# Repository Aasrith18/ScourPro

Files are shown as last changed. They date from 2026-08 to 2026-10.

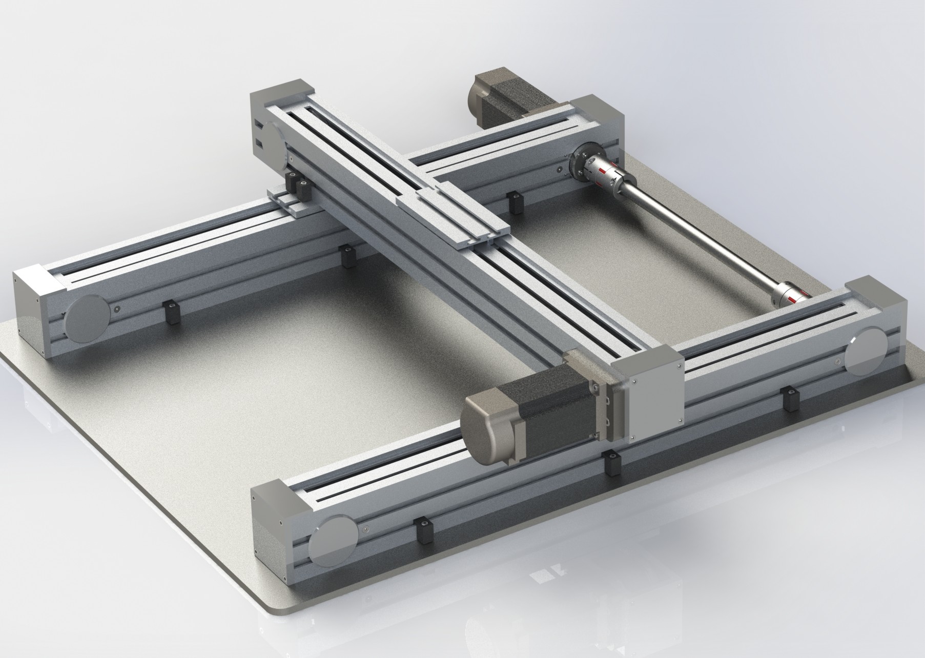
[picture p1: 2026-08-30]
CAD files/ASM-2.JPG

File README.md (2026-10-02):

# ScourPro: Automated sand bed profiler for laboratory flumes
This project is a sand bed profiler aimed specifically at scour profiling on the Hydraulic laboratory flumes. This file clearly documents the progress of this project (failures & the knowledge acquired from them) and also outlines the requirements, scope and direction for the final product.

### Visual Prototype: Hero image, Project overview, Output visualization

<p align="center">
  <em>Final product visualization</em>
</p>

<p align="center">
  <em>Product overview with major components, features & specifications</em>
</p>

<p align="center">
  <em>Expected output visualization</em>
</p>

## Table of Contents

1. [Introduction](#1-introduction)
2. [Components Used](#2-components-used)
3. [Work Done So Far](#3-work-done-so-far)
4. [Wiring Diagram](#4-wiring-diagram)
5. [Hardware Instructions](#5-hardware-instructions)
6. [Code Overview](#6-code-overview)
7. [Future Plans](#7-future-plans)
8. [License](#8-license)
9. [Repository Structure](#9-repository-structure)
10. [Credits & Acknowledgements](#10-credits--acknowledgements)

## 1. Introduction
This project aims to speed up the surface profiling process on the laboratory flumes by automatically moving a sensor, along x-direction (width) and y-direction (length), which measures the depth (z-direction) of the sand bed surface. 

## 2. Components Used
A detailed Engineering Bill of Materials (EBOM) is provided [here](https://docs.google.com/spreadsheets/d/1VOksqOdsrbbUIk9T7hXksDzNJ4-1fR_ZSVMrzwDk07w/edit?usp=sharing).

| Components (embedded) | Quantity | Notes |
|---|---|---|
| Raspberry Pi Pico| 1 | Micro controller |
| NEMA17 stepper motor| 3 | Stepper motor |
| A4988 Stepper Motor Driver Module| 3 | Stepper motor driver |
| 24V 5A DC Power Supply Adapter | 1 | Main power source |
| DC-DC Automatic Boost Buck Converter Board  | 1 | Power source for servos |
| Misc. components | ~ | Jumper wires, breadboard, etc. |

| Components (hardware) | Quantity | Notes |
|---|---|---|
| 2020 V-Slot Aluminium Extrusion Profile 1000 mm (For frame) | - | - |
| V-Wheel Kit & Connecting Plates (For custom mounting) | - | - |
| 3D Printed Parts | - | Provided in `/CAD files` folder  |
| Misc. Hardware | - | Screws, bearings, etc. |

## 3. Work Done So Far
I started this project with - a stepper motor (NEMA17), stepper motor driver (DM556), microcontroller (Raspberry Pi Pico 2), 24V power supply.
Using DM556 stepper motor driver was an overkill so it was replaced with A4988 stepper motor driver.
After a lot of effort, the correct wiring for the NEMA17 motor was figured out. It is shown in the [wiring diagram](#4-wiring-diagram) section below.

After the raspberry pi pico 2 is burnt (my bad), I shifted to raspberry pi pico (coz I didn't see any difference between them, at least for the project requirements 🤷‍♂️).
Testing was then done with a 12V power supply and A4988 stepper motor driver. The code file along with the libraries used is shared in the [code overview](#6-code-overview) section below.

After testing different options for the achieving higher speeds for the motor, these parameters are suggested. (just a suggestion)
24V power supply, 1-1.2 A current (adjustable on A4988 motor driver).

The initial version of this project was quite flimsy but good enough to work with during motor testing. I've uploaded a video (sped up) from when the motor first worked.
Although, there are some **important** things to note regarding the codes given in this repo {[code overview](#6-code-overview)}:
- The 323 revolutions, hardcoded, is the total number of revolutions it takes to get from one end of the lead screw to the other (found out the hard way 😮‍💨). You may or may not need this. So to you, this is a variable you need to adjust after the hardware is setup. If you don't want to hardcode it and provide input options for width and length to be covered, then that would be great as well.
- The steps per revolution are 400. I've tried decreasing and increasing them but the motor either stopped or made a lot of noise. I couldn't figure out why the others weren't working even though I adjusted both motor driver and the code accordingly. (lack of knowledge on my part. you can still give this a try. 🙂)
- During the "Phase 2" of the motor movement (check in code), the motor is coded to stop for 1 sec after every 10 revolutions. This was done when the sensor was not in picture. And different experiments may require different resolution while taking a reading. And there's another thing to consider - the "tracking" feature of the sensor (basically, continuous readings without us having to send transmit command every time). Leave it as it is for testing the motor, but this will change based on the hardware setup and the sensor you get.

https://github.com/user-attachments/assets/a4b7bfc3-b2b1-426d-8927-acc9cb2e59b3
<p align="center">
  <em>Initial version of working motor set up</em>
</p>

I also got a distance measurement sensor from [Meskernel LDL-10](https://www.meskernel.com/laser-distance-moudules/65904266.html). No proper documentation was available for this sensor.
It is pretty easy to use with a USB connection but I couldn't figure how to use it with a UART connection.
Unfortunately, till date, this sensor is the only feasible option we have. So if you're going to use it.. all the best 👍

In that (worst case) scenario, here are some notes regarding the sensor:
- The module I used was U85B, it only worked with the baud rate of 19200.
- For using it with USB connection, you need to download the [meskernel software](https://lasersensor.net/en/download/software/).
- This module had an RTS pin. I never found out what it is or does. Nor did I find any documentation of this sensor mentioning an RTS pin. 🧐 
So I never got to use it with a UART connection and the sensor got damaged before I could figure it out.
- Other modules may come with other problems, I'll let you discover them. 😄

Sensor readings on software
<p align="center">
  <em>Test readings I took with USB connection</em>
</p>

## 4. Wiring Diagram
wiring_img
<p align="center">
  <em>Wiring Diagram for the NEMA17 motor with A4988 stepper motor driver</em>
</p>

## 5. Hardware Instructions
The [CAD files](/CAD%20files/) folder contains all the necessary files. But, before you print them out, make sure to check the dimensions. The files were made with a general idea of the product and not tailored to a specific flume dimensions. Please pick a flume you wish to work on and alter the dimensions accordingly 🙂 I suggest you first run a trial with 3D printed components before fabricating any metal components.

## 6. Code Overview
This project involves MicroPython code file (singular) to communicate with the A4988 motor driver. I've uploaded the file in this repository.
I also uploaded the file to communicate with DM556 motor driver as well (just in case). The code paths are below.

> 📁 Code Path: [`rasppi-a4988.py`](rasppi-a4988.py)

> 📁 Code Path: [`rasppi-dm556.py`](rasppi-dm556.py)

Two libraries **(machine and time)** are used in the code.
- Machine library:
  What it is: The machine library is a core MicroPython module used to directly interact with the microcontroller's physical hardware.
  What it is doing in this code:  Pin Initialization - It designates the Raspberry Pi Pico's GPIO pins (Step, Direction, Enable, and the onboard LED) as output pins using machine.Pin.OUT.
  Digital Signaling: It toggles these pins High or Low (using .on(), .off(), and .value()) to physically communicate with the A4988 driver. This manages the motor's spin direction, actively enables or disables the driver module, and triggers the physical step actions. 

- Time library:
  What it is: The time module handles time-tracking, scheduling, and blocking delays.
  What it is doing in this code:  Precise Motor Pulsing (Microseconds): It uses time.sleep_us() to create extremely short, calculated microsecond delays. This is used to form the active 25% duty cycle step pulses required to accurately turn the motor at a specific frequency.
  Sequence Pacing (Seconds): It uses the standard time.sleep() function to introduce longer pauses. This controls the 1-second gaps when blinking the Pico's LED to signal startup, as well as the programmed 1-second resting periods every 10 revolutions during the motor's second phase of movement.  

## 7. Future Plans
- Find a feasible sensor that meets the following requirements:
  - Precision: 1 mm
  - Accuracy: +/- 1 mm
  - Range: 1-2 m
  - Should be able to detect the distances of granular surfaces like sand
  - Should have robust documentation
  - Should detect distances of a point, instead of averaging out the entire field of view.
  - Laboratory purposes. Need not be industrial.
  - Budget friendly
- Fabricate light weight metal (aluminum mostly) components for hardware and assemble them together.

## 8. License
Licensed under the **GNU General Public License v3.0 (GPL-3.0)**.  
See the [LICENSE](./LICENSE) file for full details.

## 9. Repository Structure

```text
ScourPro/
├── CAD files/            # 3D printed parts and custom mounting CAD files
├── .gitignore            # Git ignore rules
├── LICENSE               # GNU GPL-3.0 License
├── Product_Specs.md      # Product Requirements & Specifications Document
├── README.md             # Project documentation, wiring specs, and future scope
├── rasppi-a4988.py       # MicroPython script for Raspberry Pi Pico with A4988 driver
└── rasppi-dm556.py       # Alternative MicroPython script for DM556 driver
```

## 10. Credits & Acknowledgements

* **Project Guidance:** Special thanks to **Prof. Dhrubajyoti Sen** and the **Hydraulics Laboratory, Department of Civil Engineering** for their continuous support, mentorship, and resources throughout the development of this project.
* **Open Source Community:** Grateful to the MicroPython core development team for providing robust libraries (`machine`, `time`) that simplified microcontroller interfacing.
* **Hardware & Components:** Acknowledgements to the manufacturers and hardware suppliers for providing open specifications and modules (Raspberry Pi Foundation, Allegro MicroSystems for the A4988 driver).

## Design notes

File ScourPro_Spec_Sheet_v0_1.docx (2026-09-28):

ScourPro

Automated Scour Surface Profiler — Product Specification Sheet — Proof-of-Concept (P1)

Document ID | SCOURPRO-SPEC-P1-v0.1
Status | DRAFT — duplicate this file per revision
Prepared by | TBD
Reviewed / Approved by | TBD
Date | TBD
Applicable prototype | P1 (Proof-of-Concept)
Target users | Indian hydraulics research & teaching labs (IITs, NITs, CWPRS)

How to use: fill Target values at design freeze; fill Measured values only from documented tests (link test report ID in Notes). Any cell left TBD blocks release sign-off. Duplicate the file and bump the version for each iteration; log changes in §12.

1. Product Overview

Product name / SKU | ScourPro
Target users | Indian hydraulics research & teaching labs (IITs, NITs, CWPRS)
Primary use case | Automated scour bed profiling after drained flume tests
Configuration | 2-axis Cartesian gantry: GT2 belt-driven X (width) and Y (length); sensor fixed (no Z motion axis)
Measurement principle | Single-point non-contact depth reading at each X–Y grid point; sensor moved over the bed, ToF reading gives depth
Mounting | Bolt-down to a fixed rail on the flume side walls
Target flume | 0.5 m (L) × 0.3 m (W) × 0.8 m (H); PoC fixed to 0.3 m width
Not-to-exceed build cost | ₹60,000 (PoC ceiling)

2. Measurement & Motion Performance

Accuracy verified after multi-point calibration against a stepped datum block, checked on a sand-textured (matte) reference surface. Report test ID in Notes.

Parameter | Minimum | Target | Measured | Test method / Notes
Motion axes | 2 | 2 (X, Y) | TBD | Belt X + belt Y; sensor fixed
Depth accuracy | ±5 mm | ±1 mm | TBD | Multi-point calibration; ISO-style repeat reads
Depth resolution / precision | 1 mm | ≤0.5 mm | TBD | Repeat reads, static target
XY positioning accuracy | ±1 mm | ±0.5 mm | TBD | Commanded vs. measured, dial gauge
X travel (width) | 300 mm | 300 mm | TBD | Full flume cross-section
Y travel (length) | 500 mm | 500 mm | TBD | Along flume length
Grid spacing (user-set) | 10 mm | 10–50 mm | TBD | Configurable per run
Z measurement window | TBD | TBD | TBD | Must cover full scour depth (~150 mm) from fixed height
Full-grid scan time | ≤20 min | ≤10 min | TBD | Representative grid, full area

2.1 Work Envelope

Parameter | Minimum | Target | Measured | Test method / Notes
X-axis travel (width) | 300 mm | 300 mm | TBD | Hard stop + soft limit values
Y-axis travel (length) | 500 mm | 500 mm | TBD | Hard stop + soft limit values
Sensor standoff height | TBD | TBD | TBD | Fixed; set to cover full depth range
Flume width compatibility | 0.3 m | 0.3 m | TBD | PoC fixed; adjustable is a later item

3. Actuation & Transmission

Parameter | Minimum | Target | Measured | Test method / Notes
Motor type (X, Y) | TBD | TBD | TBD | Stepper; NEMA 17 class expected
Driver | TBD | TBD | TBD | A4988 / TMC2209 class; driven by Pico
Transmission (X) | GT2 6 mm belt | GT2 6 mm belt | TBD | Open-ended, anchored both ends
Transmission (Y) | GT2 6 mm belt | GT2 6 mm belt | TBD | Dual-side drive to resist racking
Homing / limit switches | Required (both axes) | Required (both axes) | TBD | Home every run for repeatable origin
Power-off position hold | TBD | TBD | TBD | Belt is not self-locking; evaluate need

4. Materials & Structure

General structure | V-slot aluminium extrusion (frame doubles as linear rail)
Brackets & mounts | 3D-printed (PETG/ASA recommended; document print params)
Linear motion | V-wheels on extrusion; eccentric spacers for preload
Moisture / corrosion | Splash-resistant only (bed is drained before use)
Prohibited | PLA in load-bearing structural paths (creep)

Acceptance criterion: positioning and depth-accuracy specs in §2 govern structural adequacy — not material choice per se.

5. Electrical & Power

Parameter | Minimum | Target | Measured | Test method / Notes
Input supply | 12 V DC | 24 V DC | TBD | Single PSU; state final value at build
Logic supply | 5 V | 5 V | TBD | Buck converter from main rail; do not power Pico off motor rail
Controller | RPi Pico | RPi Pico | TBD | Drives steppers via drivers
External interface | USB | USB (PoC) → Wi-Fi (final) | TBD | USB to laptop for PoC; Wi-Fi is a later item
Driver decoupling | Required | Required | TBD | Bulk capacitor across each driver motor-supply
Inline fuse | Required | Required | TBD | On main supply

6. Control & Software

Parameter | Minimum | Target | Measured | Test method / Notes
Firmware | MicroPython | MicroPython | TBD | On the Pico
Operation | Grid + spacing entry, start | Same, refined UI | TBD | Automated raster scan
Output format | CSV (x, y, z) | CSV + plot + heatmap | TBD | CSV for PoC; visuals in later versions
3D surface generation | Off-device (post) | Off-device (post) | TBD | Python / ParaView from CSV
Calibration | Multi-point datum block | Guided routine | TBD | Stepped block, matte/sand surface

7. Environment, Safety & Compliance

Parameter | Minimum | Target | Measured | Test method / Notes
Operating temperature | 10 °C | 10–80 °C | TBD | Indoor lab; per user spec
Ingress protection | None (PoC) | None (PoC) | TBD | Basic enclosure; no formal IP rating for PoC
Compliance | None (research PoC) | None (research PoC) | TBD | Research prototype; not a sold product

8. Mechanical & Interfaces

Flume attachment | Rail with leveling feet resting on / bolted to both side walls
Leveling | Adjustable feet; rail plane defines the Z datum for all depth readings
Sensor interface | Fixed sensor housing on the trolley (no moving Z axis)
Cable routing | Drag chain along the beam; keep cables off the moving bed

9. Reliability, Serviceability & Lifecycle

Parameter | Minimum | Target | Measured | Test method / Notes
Duty rating | Occasional lab use | Occasional lab use | TBD | Not continuous / production duty
Belt service interval | TBD | TBD | TBD | Inspect tension periodically
Spares | TBD | TBD | TBD | Printable bracket STLs published

10. Acceptance Test Matrix

Every Measured cell above must trace to a row here. One report per test, filed by ID.

Test ID | Test | Method / Standard | Pass criterion
T-01 | Depth accuracy | Multi-point datum block, matte surface, repeat reads | Within ±1 mm of target (§2)
T-02 | XY positioning accuracy | Commanded vs. measured, dial gauge | Within ±0.5 mm target (§2)
T-03 | Full-grid scan time | Representative grid over full area | ≤ target (§2)
T-04 | Homing repeatability | Repeated home + return to reference point | Origin repeatable within XY spec
T-05 | Calibration routine | Run datum-block calibration, verify fit | Residuals within depth accuracy spec
T-06 | Belt racking (Y) | Full Y travel, check beam squareness | No skew / bind across travel
T-07 | End-to-end scan | Full scan of a real scoured bed, export CSV | Complete grid, no missed points

11. Open Engineering Items

- Sensor selection on sand — confirm the chosen ToF/laser sensor holds ±1 mm on matte, possibly damp sand across the full depth range (bench test before design freeze).
- Z measurement window — fix the sensor standoff height so the depth window covers the full ~150 mm scour depth without moving; this drives the sensor spec.
- No-Z fallback — with no motion Z axis there is no contact-probe backup; decide whether a fallback is needed if the ToF underperforms.
- Belt racking on the 500 mm Y axis — single vs. dual-side drive, or a stiff enough beam; confirm before build.
- Rail leveling / datum — rail flatness along Y directly biases depth; decide leveling method vs. a per-point correction map.
- Power-off hold — belts don't self-lock; determine whether holding torque or a brake is required.

12. Revision Log

Rev | Date | Author | Changes
v0.1 | TBD | TBD | Initial PoC draft

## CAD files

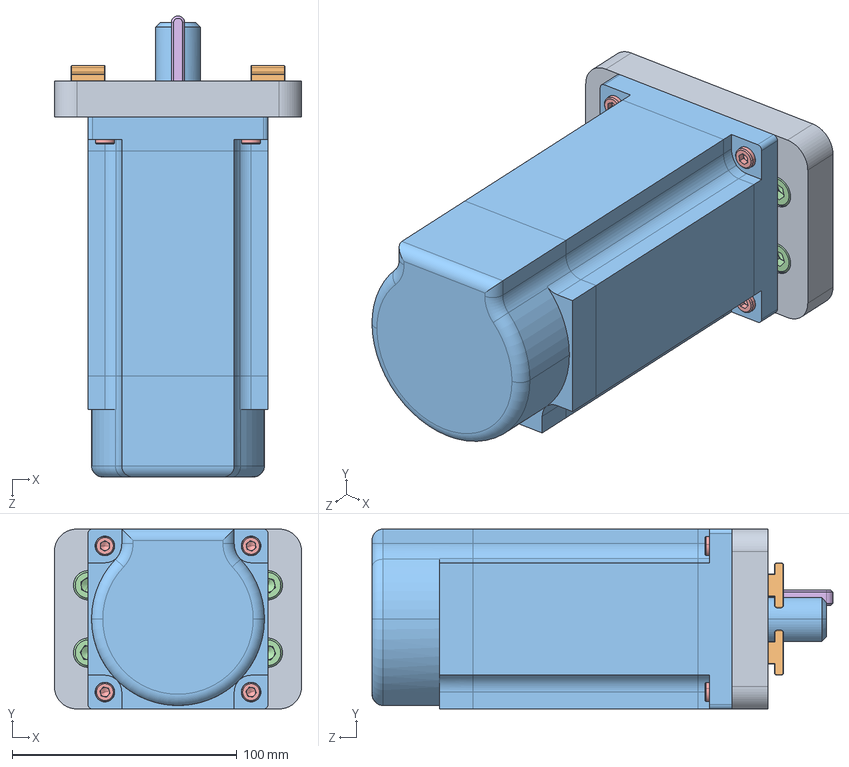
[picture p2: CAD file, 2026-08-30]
CAD files/MTR-HLD_ASM.STEP
110.0 x 80.0 x 205.0 mm
PRT-21
PRT-20 x 4
MTR
socket head cap screw_am_B18.3.1M - 8 x 1.25 x 12 Hex SHCS -- 12NHX x 4
socket head cap screw_am_B18.3.1M - 5 x 0.8 x 20 Hex SHCS -- 20NHX x 4
PRT-24

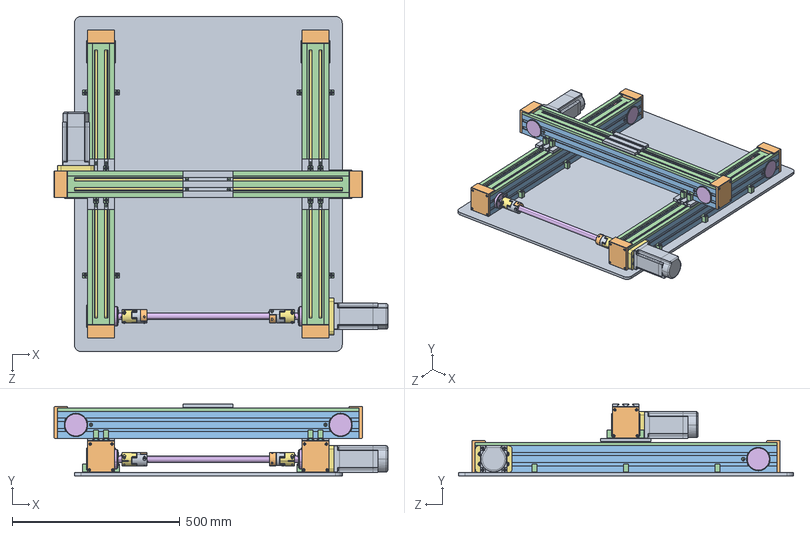
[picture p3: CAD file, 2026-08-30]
CAD files/ASM-2.STEP
996.0 x 214.0 x 1000.0 mm
BSE_PLT
PRT-1 x 6
PRT-2 x 6
PRT-18 x 3
PRT-5 x 12
PRT-4 x 6
BLT x 3
PRT-16 x 3
PRT-17 x 6
PRT-15 x 3
PRT-14 x 6
socket head cap screw_am_B18.3.1M - 3 x 0.5 x 10 Hex SHCS -- 10NHX x 24
socket countersunk head screw_am_B18.3.5M - 5 x 0.8 x 30 Socket FCHS -- 30N x 6
PRT-7 x 8
PRT-12 x 3
PRT-19 x 12
PRT-13 x 3
needle roller bearing_nm_am_AFBMA 18.1.3.4 - 45NM13 - 34,DE,AC,34 x 12
socket head cap screw_am_B18.3.1M - 5 x 0.8 x 20 Hex SHCS -- 20NHX x 32
socket countersunk head screw_am_B18.3.5M - 5 x 0.8 x 25 Socket FCHS -- 25N x 24
socket countersunk head screw_am_B18.3.5M - 3 x 0.5 x 6 Socket FCHS -- 6N x 48
PRT-6 x 2
PRT-8 x 2
PRT-9 x 2
PRT-10 x 2
PRT-11 x 2
PRT-23 x 4
socket head cap screw_am_B18.3.1M - 5 x 0.8 x 12 Hex SHCS -- 12NHX x 8
PRT-22 x 2
PRT-25
PRT-21 x 2
PRT-20 x 15
MTR x 2
socket head cap screw_am_B18.3.1M - 8 x 1.25 x 12 Hex SHCS -- 12NHX x 8
PRT-24 x 2
PRT-3 x 19
socket head cap screw_am_B18.3.1M - 5 x 0.8 x 25 Hex SHCS -- 25NHX x 19
socket head cap screw_am_B18.3.1M - 5 x 0.8 x 16 Hex SHCS -- 16NHX x 16

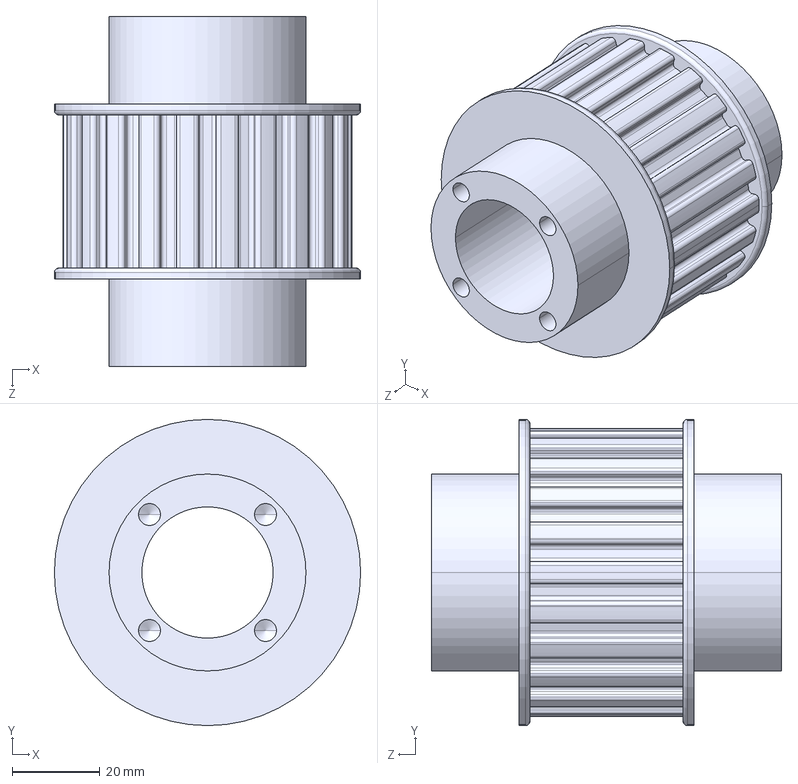
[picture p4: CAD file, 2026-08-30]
CAD files/PRT-4.STEP
70.0 x 70.0 x 80.0 mm

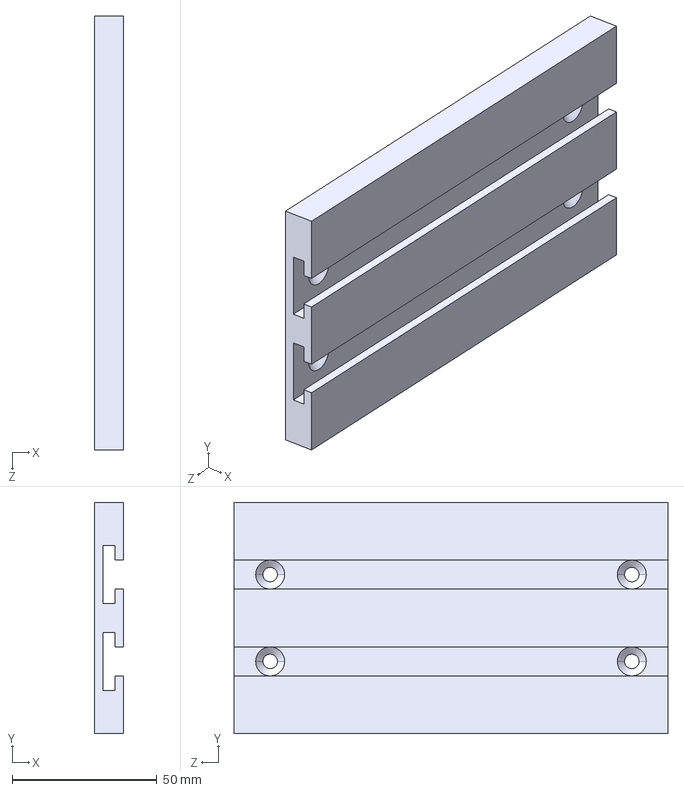
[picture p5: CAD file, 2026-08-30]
CAD files/PRT-13.STEP
10.0 x 80.0 x 150.0 mm

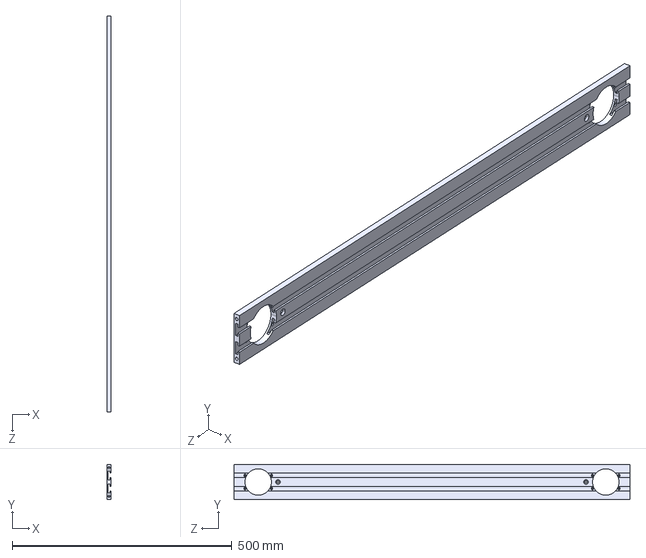
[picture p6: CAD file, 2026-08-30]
CAD files/PRT-2.STEP
10.0 x 80.0 x 900.0 mm

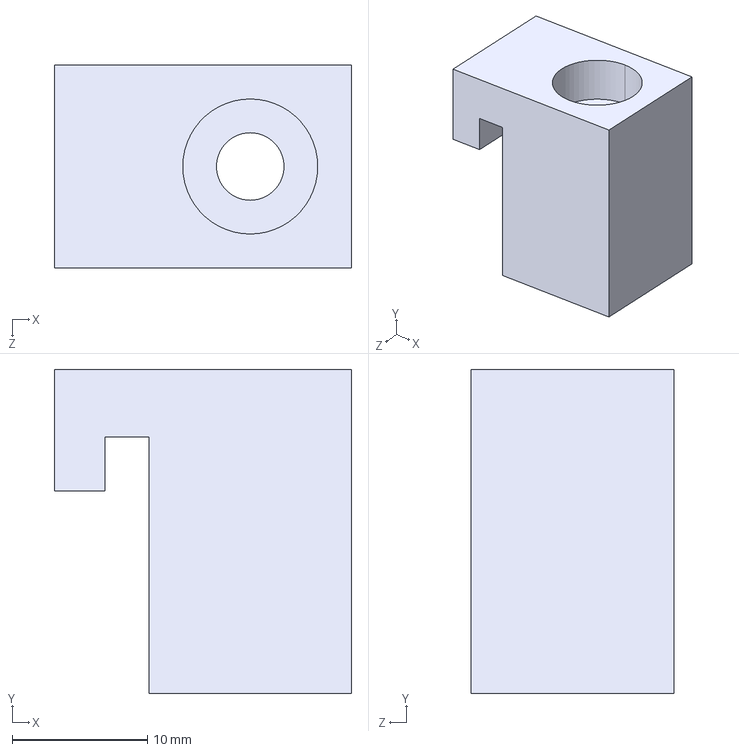
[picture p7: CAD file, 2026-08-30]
CAD files/PRT-3.STEP
22.0 x 24.0 x 15.0 mm

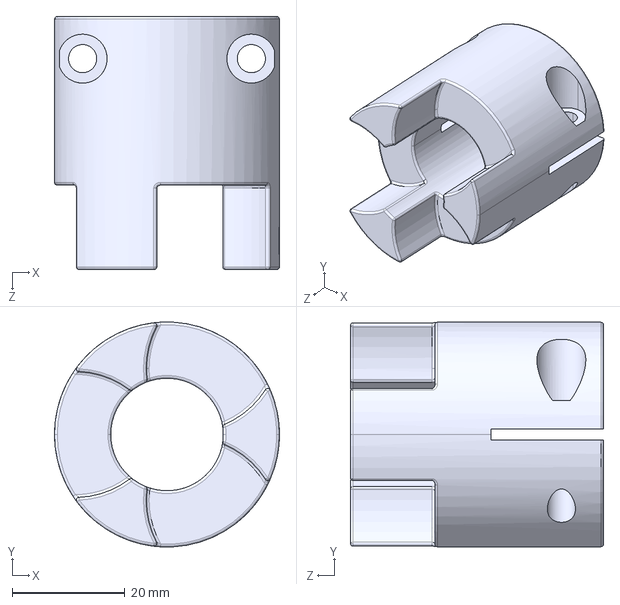
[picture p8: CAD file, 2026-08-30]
CAD files/PRT-8.STEP
40.0 x 39.9 x 45.0 mm

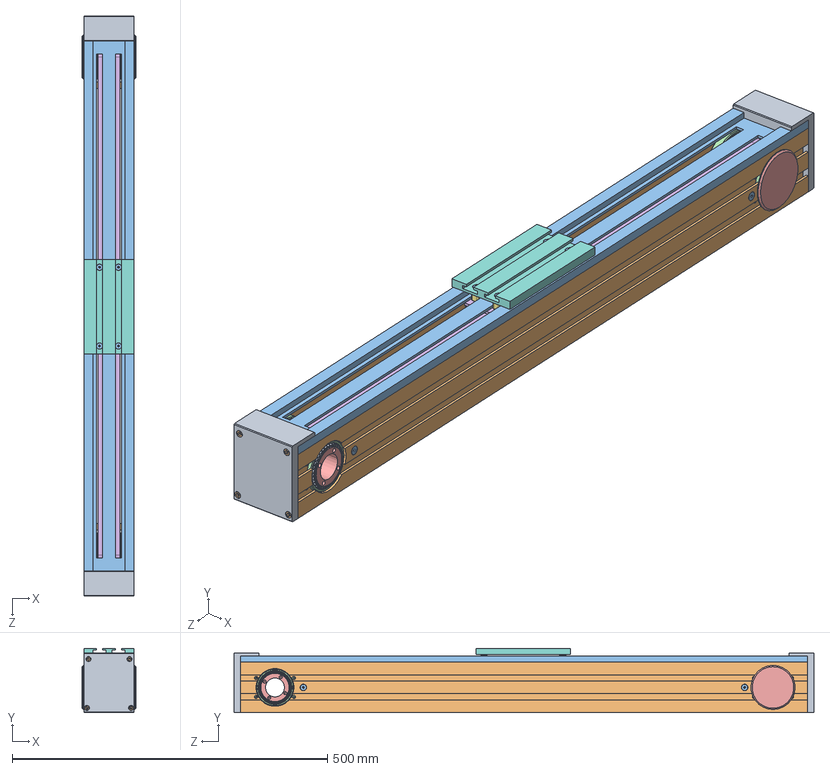
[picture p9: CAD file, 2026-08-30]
CAD files/BLT-ACT_ASSEM.STEP
86.0 x 102.0 x 920.0 mm
PRT-1 x 2
PRT-2 x 2
PRT-18
PRT-5 x 4
PRT-4 x 2
BLT
PRT-16
PRT-17 x 2
PRT-15
PRT-14 x 2
socket head cap screw_am_B18.3.1M - 3 x 0.5 x 10 Hex SHCS -- 10NHX x 8
socket countersunk head screw_am_B18.3.5M - 5 x 0.8 x 30 Socket FCHS -- 30N x 2
PRT-7 x 2
PRT-12
PRT-19 x 4
PRT-13
needle roller bearing_nm_am_AFBMA 18.1.3.4 - 45NM13 - 34,DE,AC,34 x 4
socket head cap screw_am_B18.3.1M - 5 x 0.8 x 20 Hex SHCS -- 20NHX x 8
socket countersunk head screw_am_B18.3.5M - 5 x 0.8 x 25 Socket FCHS -- 25N x 8
socket countersunk head screw_am_B18.3.5M - 3 x 0.5 x 6 Socket FCHS -- 6N x 16

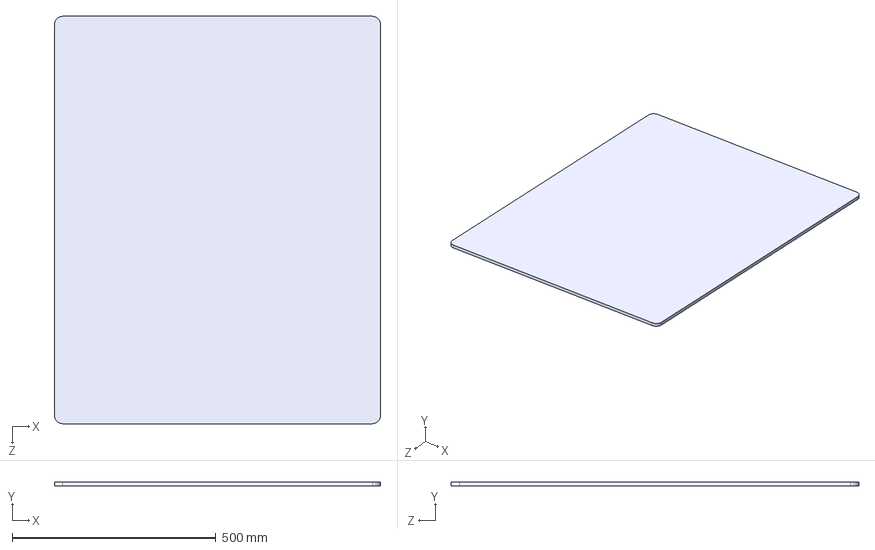
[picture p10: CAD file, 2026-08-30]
CAD files/BSE_PLT.STEP
800.0 x 10.0 x 1000.0 mm

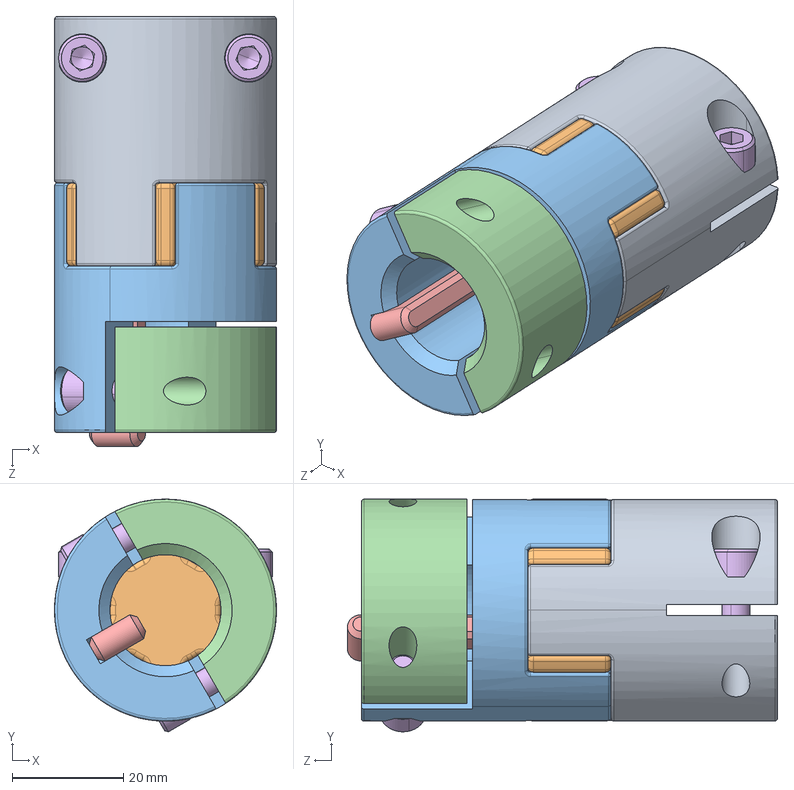
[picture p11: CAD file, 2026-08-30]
CAD files/CUP_ASSEM.STEP
40.0 x 41.9 x 77.5 mm
PRT-8
PRT-9
PRT-10
PRT-11
PRT-23
socket head cap screw_am_B18.3.1M - 5 x 0.8 x 12 Hex SHCS -- 12NHX x 4

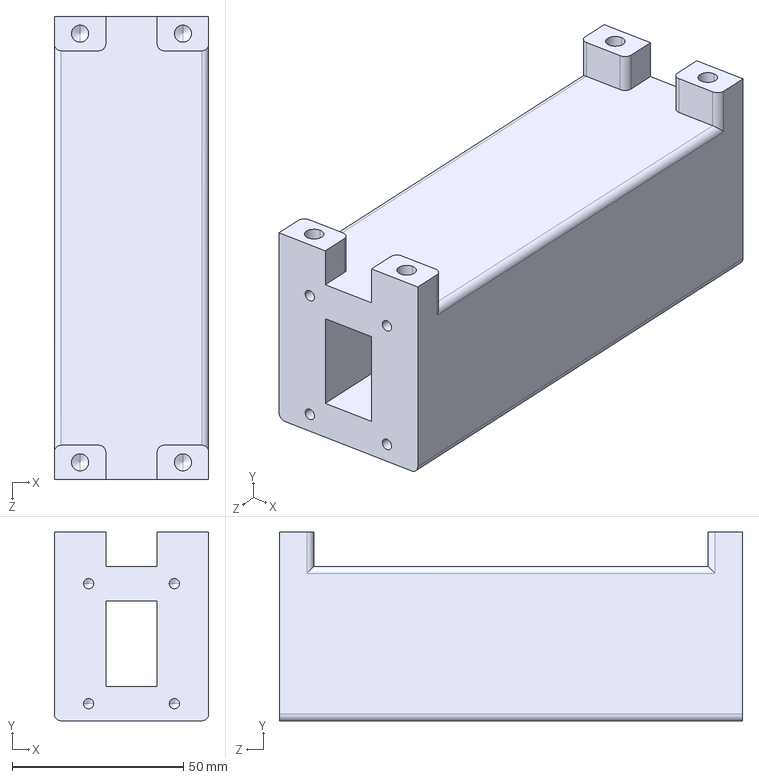
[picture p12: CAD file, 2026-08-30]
CAD files/PRT-16.STEP
45.0 x 55.0 x 135.0 mm

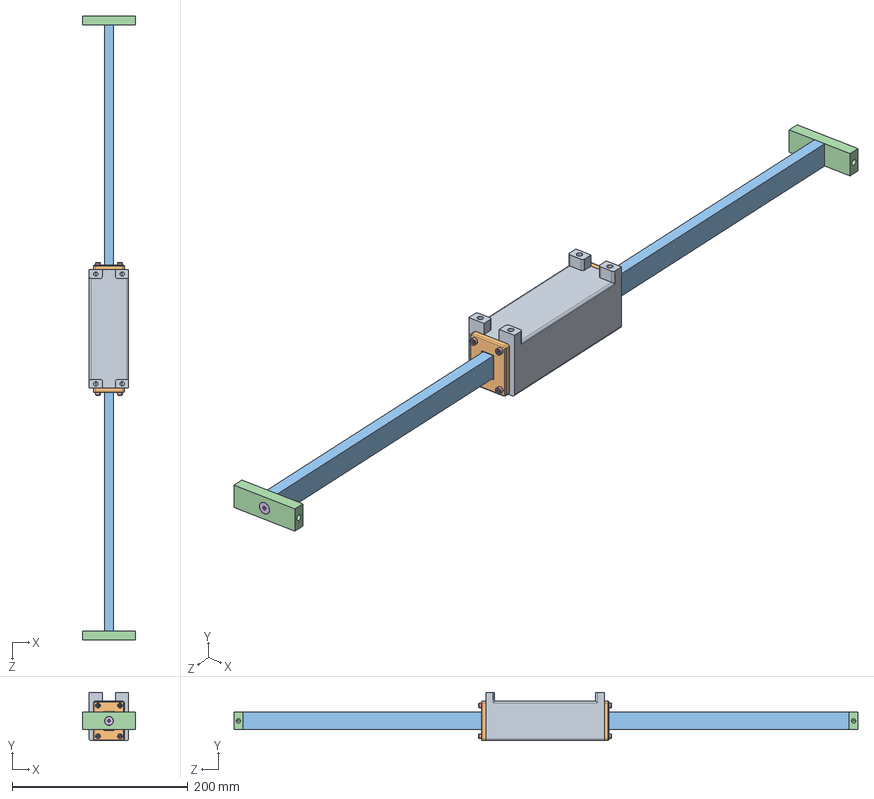
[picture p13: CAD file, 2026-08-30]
CAD files/SLD_ASSEM.STEP
60.0 x 55.0 x 710.0 mm
PRT-16
PRT-17 x 2
PRT-15
PRT-14 x 2
socket head cap screw_am_B18.3.1M - 3 x 0.5 x 10 Hex SHCS -- 10NHX x 8
socket countersunk head screw_am_B18.3.5M - 5 x 0.8 x 30 Socket FCHS -- 30N x 2

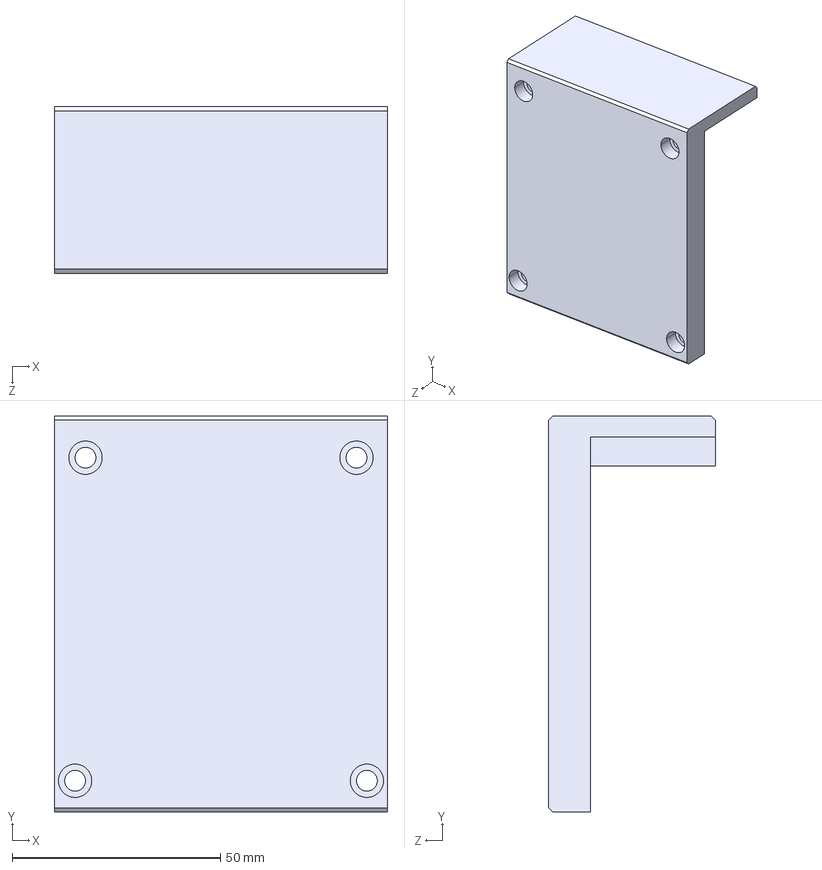
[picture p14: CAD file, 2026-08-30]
CAD files/PRT-1.STEP
80.0 x 95.0 x 40.0 mm

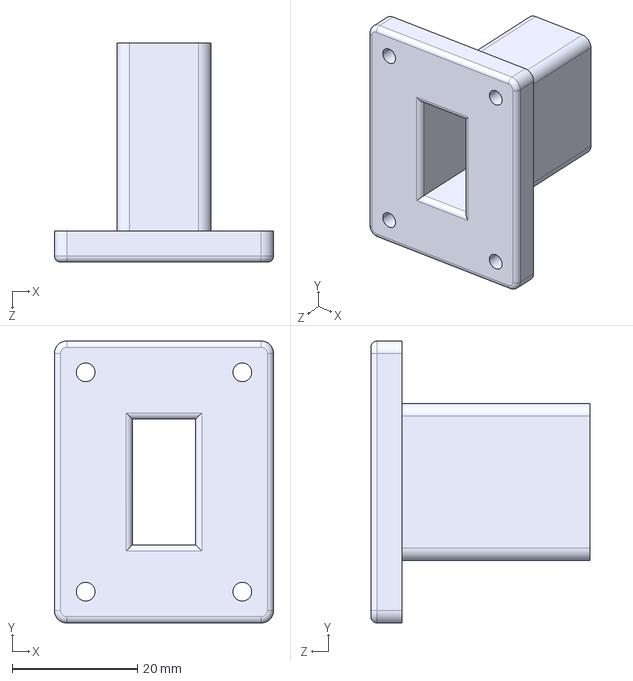
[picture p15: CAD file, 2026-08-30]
CAD files/PRT-17.STEP
35.0 x 45.0 x 35.0 mm

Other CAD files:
CAD files/PRT-22.STEP

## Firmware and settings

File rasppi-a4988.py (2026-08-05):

import machine
import time

# Pin configuration
ENABLE_PIN = 10   # Active LOW on A4988 — pull LOW to enable motor
STEP_PIN   = 11
DIR_PIN    = 12
LED_PIN    = "LED"

# Motor configuration
# A4988 microstepping (set MS1/MS2/MS3 pins or jumpers on the board):
#   Full step   → 200 steps/rev
#   Half step   → 400 steps/rev
#   Quarter     → 800 steps/rev
#   Eighth      → 1600 steps/rev
#   Sixteenth   → 3200 steps/rev
STEPS_PER_REV = 400   # Assumes half-step mode on A4988 !!DON'T CHANGE!!
DUTY_CYCLE    = 0.25  # 25%

# Setup pins
step   = machine.Pin(STEP_PIN,   machine.Pin.OUT)
dirpin = machine.Pin(DIR_PIN,    machine.Pin.OUT)
enable = machine.Pin(ENABLE_PIN, machine.Pin.OUT)
led    = machine.Pin(LED_PIN,    machine.Pin.OUT)

# Enable the driver (active LOW)
enable.off()

def blink_led(times, gap):
    """Blink onboard LED a given number of times with a gap (in seconds)."""
    for _ in range(times):
        led.on()
        time.sleep(1)
        led.off()
        time.sleep(gap)

def pulse_step(freq_hz=1000):
    """
    Send a single step pulse at 25% duty cycle.
    A4988 minimum pulse width: 1µs HIGH, 1µs LOW — well within these timings.
    """
    period_us   = int(1_000_000 / freq_hz)
    on_time_us  = int(period_us * DUTY_CYCLE)
    off_time_us = period_us - on_time_us

    step.on()
    time.sleep_us(on_time_us)
    step.off()
    time.sleep_us(off_time_us)

def rotate(revolutions, dir_val, freq_hz=1000, pause_every=None, pause_duration_s=0):
    """
    Rotate the motor for a given number of revolutions.
    """
    dirpin.value(dir_val)
    total_steps = revolutions * STEPS_PER_REV

    for s in range(1, total_steps + 1):
        pulse_step(freq_hz)
        if pause_every is not None:
            if s % (pause_every * STEPS_PER_REV) == 0:
                time.sleep(pause_duration_s)

def shutdown():
    """Disable driver to reduce heat when idle."""
    enable.on()  # Active LOW, so HIGH = disabled

# ── MAIN SEQUENCE ────────────────────────────────────────────────

blink_led(times=3, gap=1)

print("Phase 1: Rotating 323 revs, direction = 0")
rotate(revolutions=323, dir_val=0)

print("Phase 2: Rotating 323 revs, direction = 1, pause every 10 revs")
rotate(revolutions=323, dir_val=1, pause_every=10, pause_duration_s=1)

shutdown()
print("Done!")

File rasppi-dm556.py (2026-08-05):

import machine
import time

# Pin configuration
PULSE_PIN = 16
DIR_PIN = 17
LED_PIN = "LED"  # Onboard LED for Pico 2

# Motor configuration
STEPS_PER_REV = 400
DUTY_CYCLE = 0.25  # 25%

# Setup pins
pulse = machine.Pin(PULSE_PIN, machine.Pin.OUT)
direction = machine.Pin(DIR_PIN, machine.Pin.OUT)
led = machine.Pin(LED_PIN, machine.Pin.OUT)

def blink_led(times, gap):
    """Blink onboard LED a given number of times with a millisecond gap."""
    for _ in range(times):
        led.on()
        time.sleep(1)   # LED on duration
        led.off()
        time.sleep(gap)  # Gap between blinks

def pulse_step(freq_hz=1000):
    """
    Send a single step pulse respecting 25% duty cycle.
    At freq_hz, period = 1/freq_hz seconds.
    ON time  = 25% of period
    OFF time = 75% of period
    """
    period_us = int(1_000_000 / freq_hz)
    on_time_us  = int(period_us * DUTY_CYCLE)       # 25%
    off_time_us = period_us - on_time_us             # 75%

    pulse.on()
    time.sleep_us(on_time_us)
    pulse.off()
    time.sleep_us(off_time_us)

def rotate(revolutions, dir_val, freq_hz=1000, pause_every=None, pause_duration_s=0):
    """
    Rotate the motor for a given number of revolutions.
    
    :param revolutions:     Number of full revolutions
    :param dir_val:         Direction pin value (0 or 1)
    :param freq_hz:         Step frequency in Hz
    :param pause_every:     Pause after every N revolutions (None = no pause)
    :param pause_duration_s: Duration of each pause in seconds
    """
    direction.value(dir_val)
    total_steps = revolutions * STEPS_PER_REV

    for step in range(1, total_steps + 1):
        pulse_step(freq_hz)

        # Pause logic: check after completing a full revolution boundary
        if pause_every is not None:
            if step % (pause_every * STEPS_PER_REV) == 0:
                time.sleep(pause_duration_s)

# ── MAIN SEQUENCE ────────────────────────────────────────────────

# Step 1: Blink LED 3 times with 1 ms gap
blink_led(times=3, gap=1)

# Step 2: Rotate 323 revolutions in direction 0 continuously
print("Phase 1: Rotating 323 revs, direction = 0")
rotate(revolutions=323, dir_val=0)

# Step 3 & 4: Change direction to 1, rotate 323 revolutions
#             with a 1-second pause after every 10 revolutions
print("Phase 2: Rotating 323 revs, direction = 1, pause every 10 revs")
rotate(
    revolutions=323,
    dir_val=1,
    pause_every=10,
    pause_duration_s=1
)

print("Done!")

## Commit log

2026-10-02 Update README to remove wiring diagram text
    Removed wiring diagram instructions and added an image.
2026-10-02 Replace wiring diagram image in README
    Updated wiring diagram image link in README.
2026-10-02 Enhance README with wiring diagram and hardware instructions
    Added a description for the wiring diagram and provided hardware instructions for CAD files.
